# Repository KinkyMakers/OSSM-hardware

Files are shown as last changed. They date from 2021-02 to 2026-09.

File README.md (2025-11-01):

# OSSM - Open Source Sex Machine
### **Maintained by Research and Desire, supported by the community!**
### Check us out at [**researchanddesire.com**](https://researchanddesire.com)

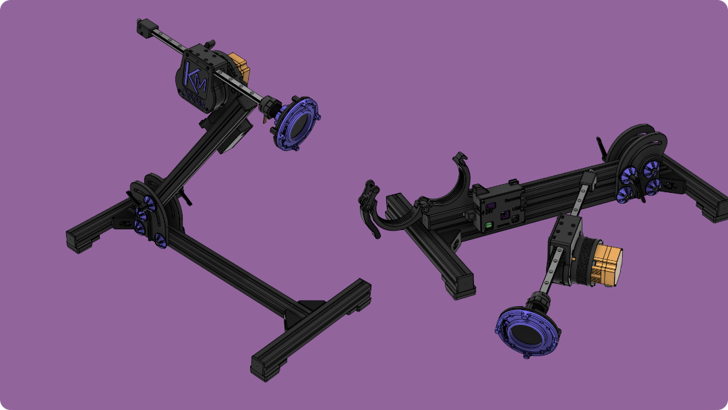
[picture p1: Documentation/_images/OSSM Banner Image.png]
OSSM Overview Image


### [**KinkyMakers Discord Community**](https://discord.gg/VtZcudpxT6) 
  
Most OSSM development takes place through ideas and CAD contributions made by enthusiastic discord members, join the discussion or show off your build!  

### Check out our docs at [GitBook](https://kinky-makers.gitbook.io/)

### [**Read the Frequently Asked Questions**](FAQ.md)

## **Summary**   
**OSSM** (pronounced like "awesome") is a user friendly every day sex machine for the people.

The OSSM's primary feature is that it is a servo powered belt-driven linear rail.  
This allows for quiet, high torque operation at speeds up to 1 meter per second, as well as for software-defined stroke and depth. 

**Standard Recommended Build at a glance**
 - 32 lbs (14 kg) of force @ 20v DC
   - Up to 50 lbs (22 kg) @ 36v DC
 - 8" Stroke (20 cm) with 350mm rail

This project aims to help people curious about sex machines explore their interest.   
A second objective is optionally learning how mechanics, electronics, physics and computing are involved in your sexual pleasure.

### **Primary** Design Goals
- Compact & quiet
- Highly performant
- Moderate cost
- 3D printable
- Easily-sourced components
- Moddable
  
<p align="center">

</p>

Note: This is a _work in progress_ and we have attempted to keep compatibility with the current BOM going
forward, but it's not guaranteed.

### Is it *actually* Open Source?
    CERN Open Hardware Licence Version 2 - Strongly Reciprocal
It is one of a kind Certified, Actual, Factual, Open Source  
[](https://certification.oshwa.org/ca000057.html)

Contributions to this GitHub repository assume the same license.

## **Safety**

The safety of the OSSM is yet to be fully characterized as it is a work in progress.  
The OSSM is a framework for building your own sex machine and as such your specific combination may have risks not inherent to other builds.  
**These risks may be undocumented or undiscovered. Please see the [Hazards](Documentation/Hazards.md) file for more information.**

Use of experimental/modified code increases the level of risk.

While using the OSSM we can suggest the following hierarchy of safety, however it is up to you and your build to decide
what risks exist and how to mitigate them.

1. Have ability to move away
2. Have ability to remove the power
3. If you are in bondage, safety is responsibility of the Top

## **Building Your OSSM**
### Motor Support  
 - 57AIM30 "Gold Motor" (Standard Recommended)
 - 42AIM30 "Round Motor" (Smaller form factor, limited mounting support)
 - iHSV57 "Legacy Motor" (Pre-2024 recommended motor)

The OSSM Software is written to support closed loop servo type motors and tested on the above motors.  
Most OSSM actuator and mounting hardware is designed for NEMA23 form factor motors.  
Attempting to use a stepper or other motor is not recommended; while it may be technically possible in some cases, this usually requires custom design work and advanced-level custom code. 

### Bill Of Materials for Standard Recommended Build

### Electronics  

 - Motor 
   - 57AIM30 ["Gold Motor"](https://www.researchanddesire.com/products/ossm-motor-gold-motor)
     - **Important note:** In order to operate with OSSM Software, motors must receive programming to set their "steps per revolution" to 800.
     - Motors from R+D are pre-programmed for OSSM. Motors from all other sources will need programming.
     - Programming requires a USB to 4 pin RS485 connector, cable for the 8 pin white motor plug, and use of the [Gold Motor Programming Tool](/Hardware/Servo%20Tools/Gold%20Motor/)
 - OSSM Reference Board, Remote, Wiring
    - [OSSM Reference PCB](https://www.researchanddesire.com/products/ossm-reference-board) or ESP32 Development Board
      - More information for board development [here](/Documentation/Board_Design.md).
    - [OSSM Remote](https://www.researchanddesire.com/products/ossm-reference-board)
    - JST-PH 2.0 4-Pin data cable and 16awg power wire
      - [Wire harness - Gold Motor](https://www.researchanddesire.com/products/ossm-wire-harness-gold-motor)
 - 20-36v DC Power Supply (5.5 x 2.1 Barrel Plug)
   - [24 volt 5 amp](https://www.researchanddesire.com/products/ossm-24v-power-supply) is recommended
   - Higher voltage, up to 36v, will provide increased force
   - USB Power Banks capable of true 100w USB PD also generally seem to operate well for a portable OSSM
     - [TESTED: ✓] INIU Power Bank P63-E1 100w (Old model: B63)
     - [TESTED: Powers down on high load] INIU B62 Power Bank 65W

### [**Printed Parts**](Printed%20Parts/) 
 - [Actuator](Printed%20Parts/Actuator/)
   - Body
   - Belt Tensioner
   - Threaded End Effector, Clamp + Nut  
 - [Remote](Printed%20Parts/Remote/)
   - Body
   - Knobs
 - [Toy Mounting](Printed%20Parts/Toy%20Mounting/)
   - Flange Base Plate with Clamping Ring (Tie-Down or Suction)
   - Double Double (Vac-U-Lock)
 - [Mounting](Printed%20Parts/Mounting/)
   - Mounting Ring (PitClamp Mini Ring)
   - Base (PitClamp Mini Base)
   - PCB Enclosure
 - [Stand](Printed%20Parts/Stand/)
   - 3030 Extrusion Base

Experimental parts pop up in the [KinkyMakers Discord](https://discord.gg/wrENMKb3) #ossm-print-testing channel.  
W.I.P. for the top rated to be merged into this repo.

### Standard Actuator Hardware
**GT2 Pulley** 

    (Qty 1) 8mm Bore, 20 Tooth, 10mm Width
**GT2 Timing Belt** 

    (Qty 1) 10mm Width, 500mm length
**MGN12H Rail + Bearing Block**

    (Qty 1)
    Minimum 250mm
    Suggested 350mm
    Maximum 550mm

Rail length = desired maximum stroke + 180mm  
Must be MGN**12H** rail.  
H is a longer bearing block than C for greater stability. 12 indicates 12mm rail width.

**Ball Bearings**

    (Qty 6) MR115-2RS 5x11x4mm 

**Fasteners**  

    (Qty 8) M3x8  Socket Cap Head Bolt 
    (Qty 2) M3x16 Socket Cap Head Bolt 
    (Qty 1) M3x20 Socket Cap Head Bolt 
    (Qty 7) M3 Hex Nut
    (Qty 3) M5x20 Socket Cap Head Bolt
    (Qty 1) M5 Hex Nut
    (Qty 4) M5x35 Socket Cap Head Bolt 
    (Qty 4) M5 20mm Hex Coupling Nut (Or M5 Hex Nut)

**Additional hardware is required for Stand, Mounting, Remote  
Detailed in their respective [Printed Parts](Printed%20Parts/) folder**

## Assembly

**Important note:** The actuator rail direction is critical for pattern accuracy and safety functions. The proper direction is with the threaded end to the right when looking at the front face of the actuator body - the "M" side of the OSSM text on the Cover.  
Outdated videos and documentation may show different directions. Your rail should extend the threaded end first when booted; if this does not match the behavior of your build you should reverse your rail's printed hardware.

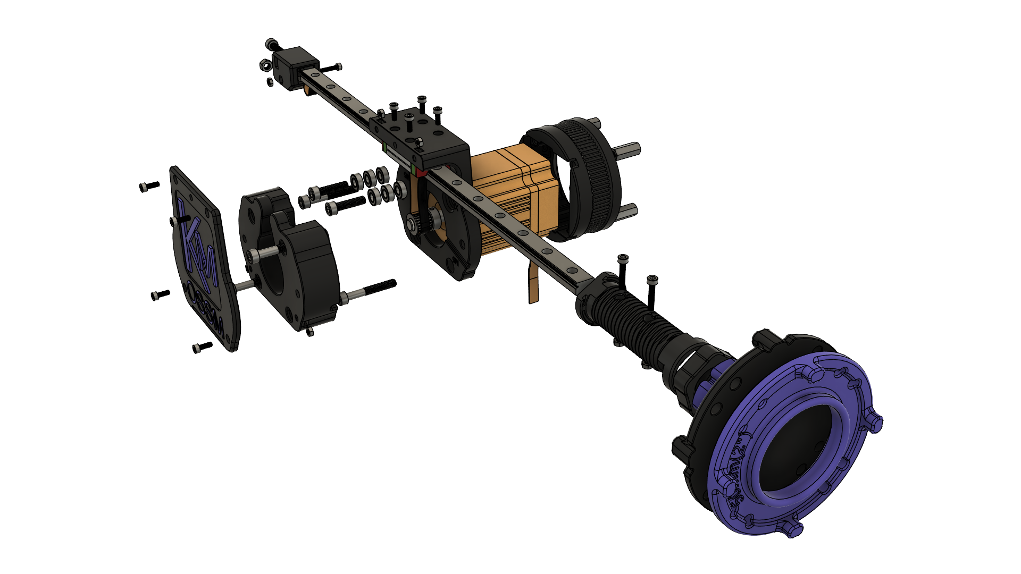
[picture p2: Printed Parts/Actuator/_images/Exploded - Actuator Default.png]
  
### [**Build Instructions**](Documentation/Assembly%20Instructions.pdf)
(03.30.2025) Note: There have been recent improvements to the OSSM Standard Recommended build that are not yet reflected in this build document.  
Refer to exploded views from the Printed Parts folders for assembly of each major component.
## Build Videos

[OSSM Assembly Playlist](https://youtube.com/playlist?list=PLzSK7OAu3KNQsFo6WJGT8P28lfkD3xpps)

[OSSM Complete Assembly - Follow Along Guide](https://www.youtube.com/watch?v=9lVobSEw_Uw)

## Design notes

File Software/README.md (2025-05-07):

## Requirements:
- PlatformIO
- ESP32 microcontroller

If you aren't sure what ESP board to select in PlatformIO, choose "ESP32 Dev Module" - it works on all ESP32 I have tested so far.

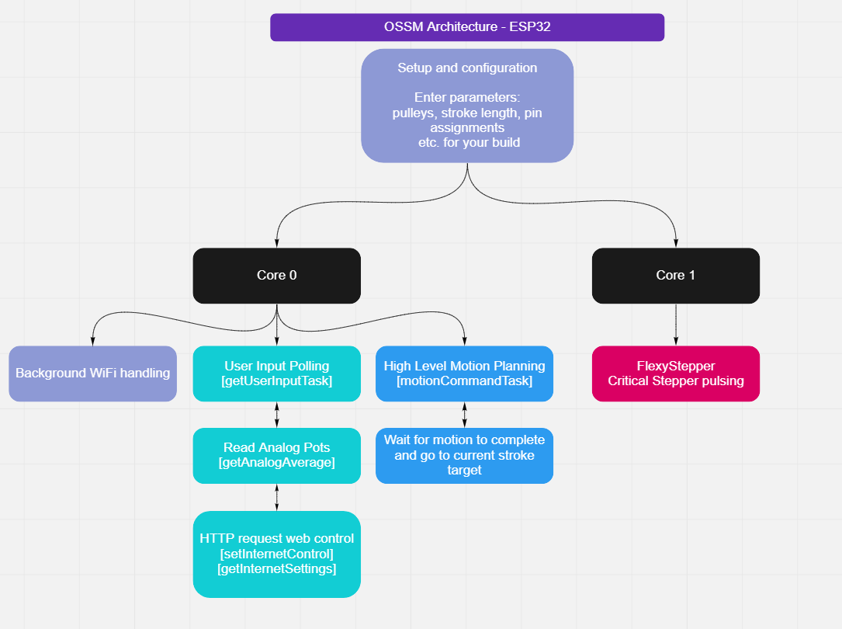
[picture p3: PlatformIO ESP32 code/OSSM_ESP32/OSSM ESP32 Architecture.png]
ESP32 Architecture


## Logging

This project uses ESP32's [native logging library](https://docs.espressif.com/projects/esp-idf/en/stable/esp32/api-reference/system/log.html).

## Commands

**Upload and monitor**
```bash
pio run -t upload -t monitor
```

**Run Unit Test tests**
```bash
pio test -e test
```

## Other Documentation
- [Git Branching Strategy](docs/Git Branching Strategy)

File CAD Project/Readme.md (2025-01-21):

    Work in progress.
    
    TODO: 
      3030 Extrusion Stand Assembly
      Add "OSSM - Mod" multiple-component project template
      Determine if Hardware components should be "independent"
        For now - designer's preference
        Independent could allow a scripted hardware count

# Design Guidelines For Contributions

- **Template**: Contribution basic template is located in [./Templates/](Templates)
    - Replace "Project Name" in Document and Component with your Project Name

User-contributed Projects with a file structure following these guidelines will allow for the easiest incorporation into an official OSSM release.

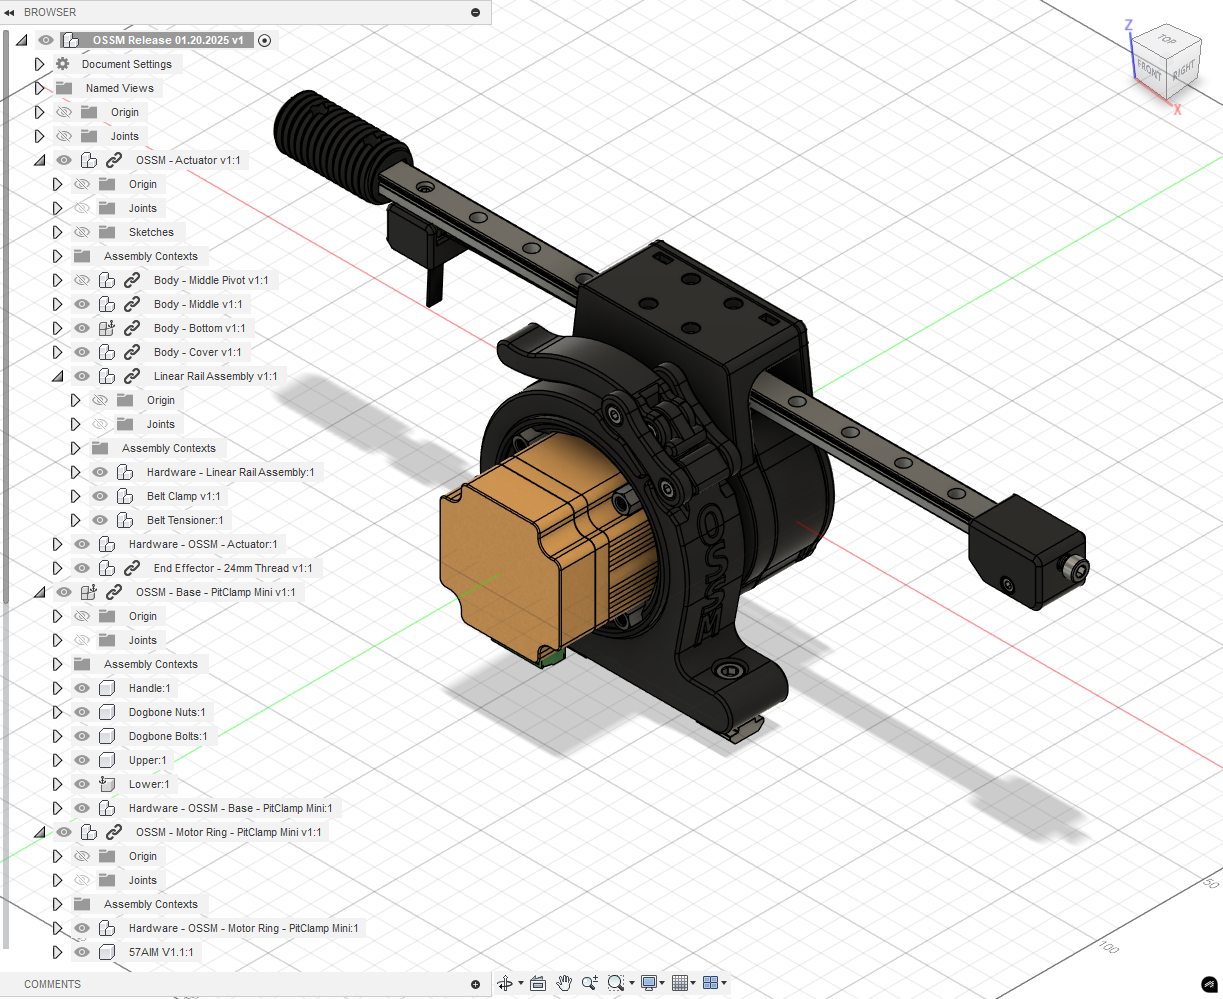
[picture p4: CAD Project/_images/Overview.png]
CAD Project Overview


## Fusion File Structure:
    ProjectName
        (Bodies)
          <empty>
        (Component)ComponentNameOne
          (Bodies)
            ...
        (Component)ComponentNameTwo
          (Bodies)
            ...
        (Component)Hardware - ProjectName 
          (Bodies)
            <empty>
          (Component)HardwareName:1
            (Bodies)
              ...
          (Component)HardwareName:2
            (Bodies)
              ...

## Naming Conventions

- **Disallowed/Special-Use Characters**: These characters are reserved for special behavior for documentation scripting and have rules for being part of the Document or Component names.
  - `.` Designates file extension (dot)
    - Allowed for use in versioning e.g. `V1.1`
  - `-` Designates parent-child Component relationship
    - Allowed for use in hardware names e.g. `M5 T-Nut`
  - `_` Designates a Component (underscore) *[Disallowed]*
  - `[]` Designates reuse of hardware (brackets)
  - `()` Designates special hardware instructions (parentheses)

- **Single Component Project**: If your Project will only have a single Component for printing, it should contain only one Component named identical to the ProjectName.

- **Parent-child Component Relationship**: If your part should be considered as a primary item for a Parent Component, indicate this by referencing the Parent Component by exact name, followed by ` - ` and then the name of your Child Component.
  - Example: `End Effector - 24mm Short` will cause the release file to be located in the 'End Effector' directory of files, named '24mm Short'.
  - At this time, only one Parent-child relationship is allowed per Document, and must be on a single level.
    - *Documents may be nested as linked Components for more complex Parent-child relationships.*

- **Version Increment**: If your part is an update from the initial release, append ` V#.#` (uppercase, case sensitive) to the Component Name, representative of Major.Minor updates.
  - Example: `Ring V1.1`

- **Includes Hardware**: If your part requires hardware, all hardware should be nested as Components in a single top-level Component `Hardware - ProjectName`
  - Example: `Hardware - Body - Middle` where `Body - Middle` is the ProjectName

- **Reused Hardware**: If your part reuses hardware from a part it will be replacing, note this by appending ` [From:{Component}]` to the Component name.
  - Example: `M3 x 8 Cap Head Bolt [From:OSSM - Body - Middle]`

- **Alternative Hardware**: If an alternative hardware can be used, note this by appending ` ({Specification} alternative)` to the Component Name.
  - Example: `M4x12 Cap Head Screw (M4 x 10 alternative)`

- **Variant Hardware**: If hardware should vary for a different type of hardware a user could have, note this with `({Specification} for {variant},{Specification2} for {variant2})` in the Component Name. 
  - Example: `(M6 x 15 Cap Head Screw for 3030 Extrusion,M6 x 20 Cap Head Screw for 4040 Extrusion)`

## Running a Release from Fusion

This section serves as documentation for OSSM Project Leads.

There is a proof of concept "Release" process that may evolve over time, but it relies on the above conventions being followed strictly.

### Future Work:
- Convert `.stp` to `.stl` at high-quality refinement and bundle into `OSSM-Hardware/Hardware/OSSM Printed Parts` release.
- Generate hardware documentation from `Hardware` named component structures.

### Steps:

1. Update the Fusion Document name to `OSSM Release $MM.DD.YYYY`.
2. Export your Fusion Document as `OSSM.f3z` to overwrite the current file.
3. Run the Add-In "ExportIt" using the settings below. This will populate the `_export` directory with `f3d` and `step` folders.
4. Run `OrganizeForRelease.ps1` in a PowerShell terminal from the directory containing the `_export` folder, next to `OSSM.f3z` 
  - This will create a `RELEASE` folder with the date appended 
  - Files will be organized in a release configuration
    - `.f3d` is grouped based on Fusion nested structure
    - `.stp` is grouped based on naming convention, children grouped into parent
    - [Future] Documentation framework generated referencing files contained in `Hardware` directories 
5. Manually tidy up:
   - Move the previous release to the `_archive` folder.
   - Check for loose files in `_export` and remove them.
     - (This may suggest something went wrong generating your release)

### ExportIt Settings

#### Export Tab
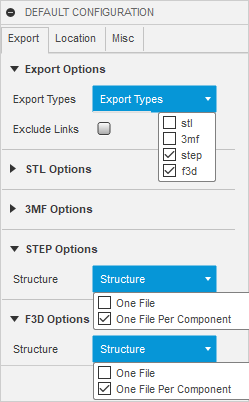
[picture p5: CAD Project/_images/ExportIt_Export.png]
ExportIt Export Tab Settings


#### Location Tab
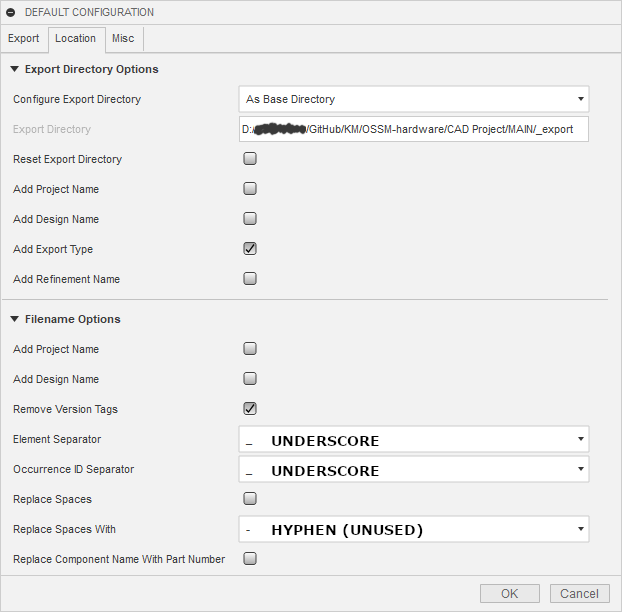
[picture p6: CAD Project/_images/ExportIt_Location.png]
ExportIt Location Tab Settings


#### Misc Tab
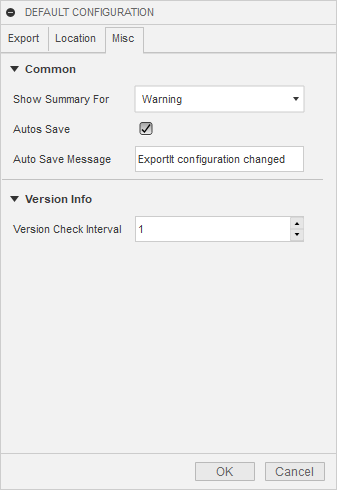
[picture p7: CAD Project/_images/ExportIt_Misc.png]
ExportIt Misc Tab Settings


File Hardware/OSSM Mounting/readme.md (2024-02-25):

# Mounting Options

There are several options for mounting your OSSM! You will find descriptions of the mounts below, and the files and instructions on how to build them in the folders above. 

The **OSSM Basic Mount** is the "official" design and is available to [purchase from Research and Desire](https://shop.researchanddesire.com/collections/all/products/ossm-basic-mount). It is mostly 3D printed and is screwed down to a piece of wood, furniture, shelf etc. It uses the 3D printed middle pivot and threaded handles. Current design relies on sourcing a length of 3030 extrusion (1.5" will also work). This is one of the less expensive options. Picture below.

rdmount

The **Shicks 4040 mount** was created by discord community member Shicks101 (Thanks!) and is made out of Aluminum Extrusion and 3D printed parts. It supports a high level of articulation and variability in height. The parts are easy to get, but it is a little more costly. You may need to weigh it down with dumbbells or sandbags. Picture below.

resized

The **OSSM Extrusion Mount** is an extrusion based mount that is simple to print and assemble requiring no cutting tools if you can get extrusion at the correct length. It uses the standard middle pivot and only a few 3D printed pieces.


**Emma's mod** is for the use of a long Nema23. This mount is mostly 3D printed and was created for a different machine, but will still work. (no photo available)  

There are a few more mounting options created by community members in the Discord that are not present here in the repository. Some are motorized! Or if none of these fit your use case, you could create your own and share it with the community.

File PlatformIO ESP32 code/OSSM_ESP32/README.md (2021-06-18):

# OSSM Software
This is the recommended software for use with OSSM designs

### Requirements:
- Arduino IDE or PlatformIO
- ESP32 microcontroller

To use with Arduino, simply open the .ino file in the src directory. You will also need to copy the folders in the lib directory to your arduino library folder on your PC.

Use the tutorial below to install the ESP32 board into your Arduino IDE so you're ready to program!

[Setting up ESP32 on Arduino IDE](https://randomnerdtutorials.com/installing-the-esp32-board-in-arduino-ide-windows-instructions/)

If you aren't sure what ESP board to select in Arduino IDE, choose "ESP32 Dev Module" - it works on all ESP32 I have tested so far.

ESP32 Architecture

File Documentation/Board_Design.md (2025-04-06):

//TODO: This document is in need of an update.

We have found that the 3.3v boards may miss steps at high speed, so please use a level shifter as well.  
To start working on the project, something like this [Adafruit board](https://www.adafruit.com/product/3405) is an excellent place to start.  
Accessories required for prototyping
    include [Breadboard](https://www.amazon.ca/Breadboard-Solderless-Prototype-Distribution-Connecting/dp/B01EV6LJ7G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)
    and [Dupont Jumpers](https://www.amazon.ca/120pcs-Multicolored-Breadboard-Arduino-raspberry/dp/B01LZF1ZSZ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)

## Official OSSM Wiring

OSSM reference board front  

The above image is of a version 1 reference board.

### OSSM PCB Connections

OSSM PCB connection diagram

### GPIO Layout

OSSM pinout diagram
JST Header location with pin labels

## Non-Official OSSM Wiring

This should be a good start for the wiring of your OSSM! However, depending on your hardware mix settings or wiring may
be different

### OSSM PCB w/ TB6600 Stepper Driver

OSSM PCB w/ TB6600 Stepper Driver

### Servo Wiring

Servo Wiring

### Stepper Wiring

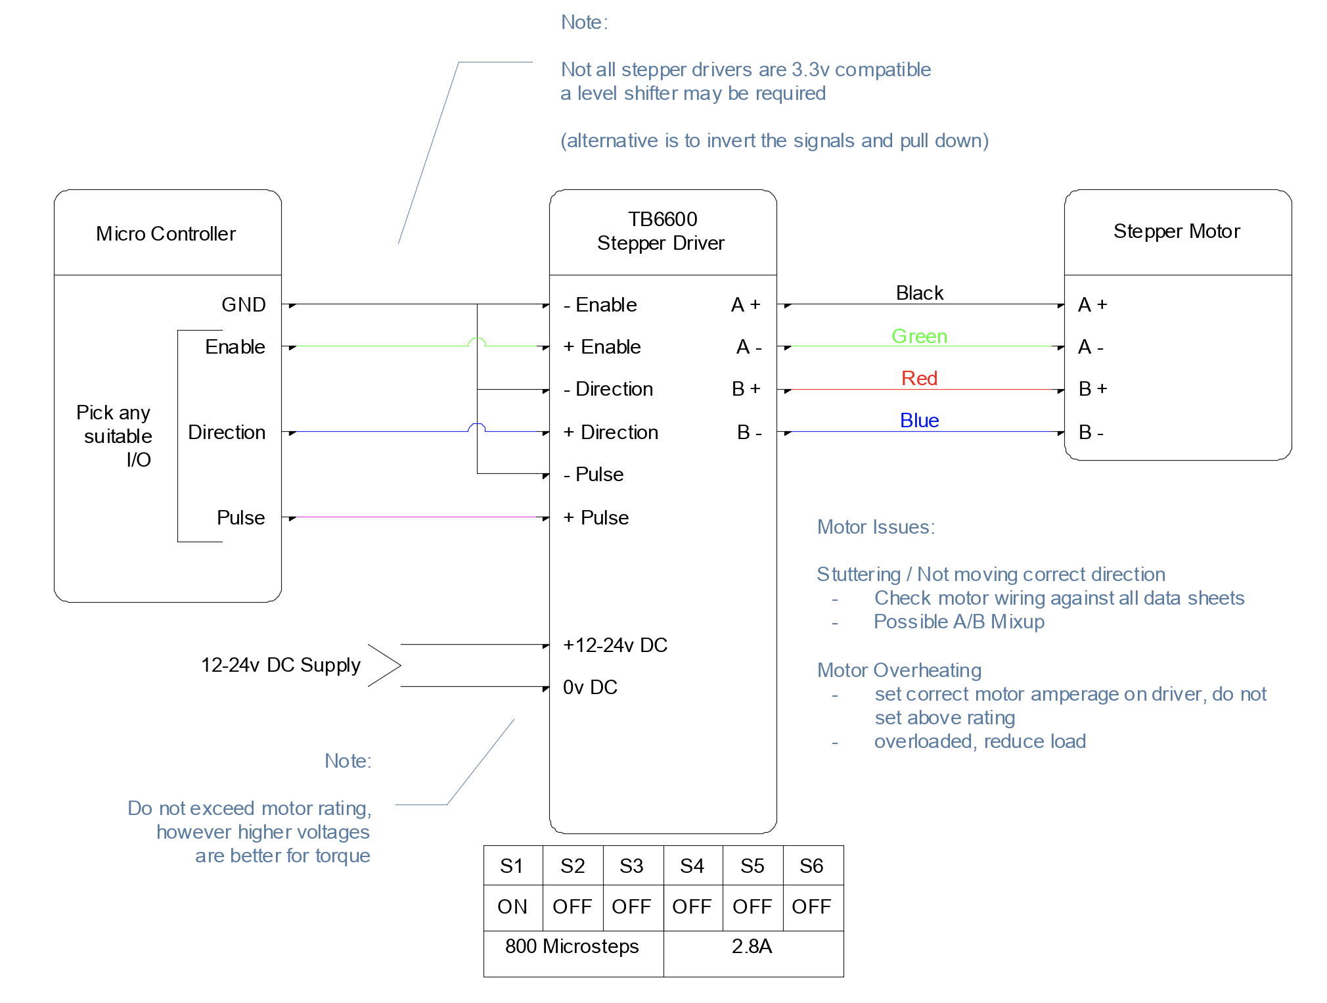
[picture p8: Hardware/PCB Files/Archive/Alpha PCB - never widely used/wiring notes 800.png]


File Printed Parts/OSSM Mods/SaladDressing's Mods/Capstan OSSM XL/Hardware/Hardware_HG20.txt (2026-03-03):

4x M4x12 ISO7380

2x M5x45 Countersunk
4x M5x75 Countersunk
4x M5x20 Hex Cap
2x M5x25 Hex Cap
3x M5x30 Hex Cap
4x M5x65 Hex Cap
1x M5x110 Hex Cap Fully threaded https://de.aliexpress.com/item/1005005879037174.html?gatewayAdapt=glo2deu

11x M5 Nuts
4x M4 Nuts

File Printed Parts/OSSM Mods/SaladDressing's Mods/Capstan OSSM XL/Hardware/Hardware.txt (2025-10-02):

5x M3x12 Hex Cap
2x M3x16 Hex Cap
4x M4x12 ISO7380
4x M5x45 Hex Cap
1x M5x80 Hex Cap Fully threaded
6x M5x45 Countersunk
1x M5x12 ISO7380
2x M5x20 ISO7380

13x M5 Nuts
3x M3 Nuts
4x M4 Nuts

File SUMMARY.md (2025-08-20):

# Table of contents

* [OSSM - Open Source Sex Machine](README.md)
* [Contributor Covenant Code of Conduct](CODE_OF_CONDUCT.md)
* [Contributing to OSSM (Open Source Sex Machine)](CONTRIBUTING.md)
* [Frequently Asked Questions](FAQ.md)
* [CAD Project](<CAD Project/Readme.md>)
  * [MAIN](CAD Project/Main/README.md)
    * [OSSM CAD Project Release Notes](<CAD Project/MAIN/RELEASE_NOTES.md>)
* [Documentation](Documentation/README.md)
  * [Assembly Instructions](<Documentation/Assembly Instructions.md>)
  * [Board\_Design](Documentation/Board_Design.md)
  * [New Standard Servo Motor](Documentation/Gold-Motor.md)
  * [Hazards](Documentation/Hazards.md)
  * [Safety and designing for the OSSM](<Documentation/Safety and Design Guide.md>)
* [Software](Software/README.md)
  * [OSSM Project Documentation](Software/docs/README.md)
    * [PlatformIO](Software/docs/PlatformIO.md)
  * [Include Directory](Software/include/README.md)
  * [Libraries Directory](Software/lib/README.md)
    * [StrokeEngine](Software/lib/StrokeEngine/README.md)
      * [CHANGELOG](Software/lib/StrokeEngine/CHANGELOG.md)
      * [Pattern](Software/lib/StrokeEngine/Pattern.md)
      * [Examples](Software/lib/StrokeEngine/examples/README.md)
  * [Testing](Software/test/README.md)
* [Hardware](Hardware/README.md)
  * [Mounting Options](<Hardware/OSSM Mounting/readme.md>)
    * [Deprecated - Ball Head Mount](<Hardware/OSSM Mounting/Deprecated - Ball Head Mount/readme.md>)
    * [OSSM - Basic Mount](<Hardware/OSSM Mounting/OSSM - Basic Mount/README.md>)
    * [OSSM - Extrusion Mount](<Hardware/OSSM Mounting/OSSM - Full Extrusion Mount/README.md>)
    * [Shicks 4040 mount](<Hardware/OSSM Mounting/Shicks 4040 mount/Readme.md>)
      * [Modified 4040 parts](<Hardware/OSSM Mounting/Shicks 4040 mount/aluxprofile/README.md>)
  * [Printing the parts!](<Hardware/\[LEGACY] OSSM Printed Parts/README.md>)
    * [Choose your method for attaching a toy to the OSSM](<Hardware/\[LEGACY] OSSM Printed Parts/end effector options/README.md>)
      * [24mm Threaded Option](<Hardware/\[LEGACY] OSSM Printed Parts/end effector options/24mm threaded/README.md>)
  * [PCB Files](Hardware/PCB Files/README.md)
    * [OSSM Remote V2](<Hardware/PCB Files/OSSM Remote V2/README.md>)
  * [Servo Tools](Hardware/Servo Tools/README.md)
    * [Gold Motor](<Hardware/Servo Tools/Gold Motor/readme.md>)
* [Printed Parts](Printed Parts/README.md)
  * [Actuator](<Printed Parts/Actuator/README.md>)
  * [Mounting](<Printed Parts/Mounting/README.md>)
    * [PitClamp Mini](<Printed Parts/Mounting/PitClamp Mini/README.md>)
      * [ASSEMBLY\_GUIDES](<Printed Parts/Mounting/PitClamp Mini/ASSEMBLY_GUIDES.md>)
      * [PitClamp Mini Bill Of Materials](<Printed Parts/Mounting/PitClamp Mini/BOM.md>)
      * [UPDATES](<Printed Parts/Mounting/PitClamp Mini/UPDATES.md>)
  * [OSSM - Remote](<Printed Parts/Remote/README.md>)
  * [Stand](<Printed Parts/Stand/README.md>)
  * [OSSM Mods](Printed Parts/OSSM Mods/README.md)
    * [PitClamp Mini Reinforced 3030 Hinges](<Printed Parts/OSSM Mods/PitClamp Mini Reinforced 3030 Hinges/README.md>)
    * [PitClamp Mini Reinforced Standard](<Printed Parts/OSSM Mods/PitClamp Mini Reinforced Standard/README.md>)
    * [Threaded Belt Clamp V2](<Printed Parts/OSSM Mods/Threaded Belt Clamp V2/README.md>)

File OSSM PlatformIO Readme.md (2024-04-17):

OSSM has been developed in PlatformIO.  For people used to the Arduino IDE, moving to PlatformIO can seem daunting.  Trust us that it is simpler than it looks to operate and works far better than the very basic Arduino IDE as the project grows and changes.  

This is particularly important when it comes to managing all the libraries and dependencies. This gets very complex, very quickly. Earlier builds of OSSM it was sort of possible to mash it into the Arduino IDE and get a compile happening.  It has now past the point when it is easier to teach you to use PlatformIO than it is to repackage OSSM for the Arduino at each release. 

Why? More time for coding features and easier collaboration! OSSM is moving fast. Once you get used to VSCode there are some other great features such automatic downloads from Github and linting (autocomplete for code). 

1. Start by installing VSCode and the PlatformIO extension. There are plenty of guides for this on the web.  

2. Restart VSCode wait until PlatformIO has started and look on the sidebar for this button.



3. Click "Open"



4. This will pop up 



5. Click "Open Project" and search for the OSSM directory that has platformIO.ini in it





6. In the src directiory you should find main.cpp, click on that 



7. Near the bottom of the window look for a tick (compile) and an arrow (upload) 

 

8. You can then compile or skip that step and upload directly to your board.  

What if that doesn't work?  Check the debug screen but chances are you have not selected the right Com port for the OSSM board or the wrong board for the project.  

9. COM or /DEV/TTY will vary from machine to machine. It is set here in platformIO 



11. The reference board for OSSM has an embedded "Espressif ESP32 Dev Module".

12. If the project fails to build and the upload fails DON'T PANIC! Chances are there has been some kind of external library update.  Try changing the following lines in platformIO.ini in the root of the project 

"platform = espressif32"   to "platform = espressif32@3.5.0"

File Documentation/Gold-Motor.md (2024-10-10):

# New Standard Servo Motor

## 57AIM30 - Gold Motor

We have been testing and have decided on a new motor as the build standard. It has the same mounting pattern and shaft diameter as the old motor (iHSV57-30-XX).
It is sold by Research and Desire as [Gold Motor](https://www.researchanddesire.com/products/ossm-motor-gold-motor) or available generically as 57AIM30

If you wish to order a 57AIM30, you should source a model that runs at 1500 RPM and has an RS485 interface (NOT the 3000 RPM or CANBUS versions)

Also note that if you source your motor from somewhere other than R&D, you will need to reprogram the stored settings with a USB to RS485 dongle using the scripts found [here](https://github.com/KinkyMakers/OSSM-hardware/tree/master/Hardware/Servo%20Tools/Gold%20Motor) before you can use it.

Advantages:

- Cheaper (20%) - dependant on availability and location.
- Smaller (40% length of 180W standard - i.e. 60% reduction!).
- Lighter (50% weight of 180W).
- Higher peak force (30% higher in real-world test).
- Better over-torque handling - can be configured to reduce torque output instead of disable like current 180w servo.
- Is drop-in replacement for iHSV57 series making BOM compatible.

Requirements:
- Requires V2.2 PCB or newer for  simple wiring with PH-4 cable
  - Older boards will need wires soldered to 10 pin header
  - Recommend adding 1500uF capacitor, min 50V to older boards <V2.3

Disanvantages:

- More efficient (this causes more regenerated power in some motion conditions which requires additional capacitance and handling on the PCB).
  - PCB v2.3 as currently sold by R&D or listed on this repo has added capacitor. If you are upgrading your motor, you should add the capacitor as shown below.
- Digital comms over RS485 (Not worse than current RS232, just current boards don't have the needed adapter).
- Requires software setup to see full benefits (default FW settings disable motor in over-torque condition).
- If modding your software, technically lower top speed than HSV. (Standard code speed limit is lower than gold motor limit, so not a disadvantage for regular user).

## 42AIM30 - Gold Motor 42 (variant)

In addition to 57AIM30 (Gold Motor), which fits exactly to the previous designs and specs with no extra work, there is a varient motor which has exactly same internals and specs.
The 42AIM30 (see notes above for ordering the correct model) does away with the heatsink housing and is purely the cylindrical motor with connectors at the base.

Advantages (compared to 57AIM30):

- Smaller diameter (26%) - plus cylinder vs square.
- Lighter (unknown - ~25%?) - please submit mass if you have one.

Disadvantages (compared to 57AIM30):

- Much harder to mount.
  - No _mounting ears_ to bolt through, must put exact length machine screws into face of motor.
  - Current standard housings are not compatible with 42AIM30, though there are some options available via discord.
- Suspected heat issues caused by lack of heat sink and enclosure in printed housing - more data needed.
- Lack of clear advantages over Gold Motor (57AIM30)
  - Same specs.
  - Same length.
  - Same disadvantages.
  - Changes to BOM required.

OSSM Gold Motor Wiring





OSSM Capacitor view

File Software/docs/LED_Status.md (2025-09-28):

# (WIP) RGB LED Status Indication

The RGB LED (connected to pin 25) provides visual feedback for both Bluetooth Low Energy (BLE) connection status and machine operational status.

## Status Priority

Machine operational status takes priority over BLE status:
1. **Homing** (highest priority) - Deep purple breathing effect
2. **BLE Status** (lower priority) - When machine is idle

## Machine Status Indications

### When Machine is Homing
- **Deep purple breathing effect** - Smooth breathing pattern

- Continues until homing is complete or fails

## BLE Status Indications

### When BLE Advertising (looking for connections)
1. **Rainbow effect** - 1 second
2. **Fast breathing blue** - Rapid breathing effect in blue color (10x faster), continuously while advertising
3. **Auto-dim after 30 seconds** - Dims to subtle pulsing at connection level brightness to reduce annoyance

### When BLE Connected
1. **Rainbow effect** - 1 second
2. **Fade to dim** - Blue LED fades to a low dim level (~12% brightness) and stays dimmed
3. **Communication pulses** - Subtle brightness increases during BLE communication (send/receive)

### When BLE Disconnected
- **LED Off** - No light

## Advertising Timeout Feature

To reduce visual distraction for users with wired remotes, the LED automatically dims after 30 seconds of advertising:

- **First 30 seconds**: Bright fast pulsing blue (easily visible when searching for device)
- **After 30 seconds**: Dims to connection-level brightness (~12%) with gentle pulsing
- **Purpose**: Maintains indication that BLE is available while reducing annoyance
- **Reset**: Returns to bright pulsing if BLE connection status changes

## Communication Indication

When BLE is connected and dimmed, the LED will briefly pulse brighter during:
- **Receiving commands** from connected device
- **Sending responses** back to connected device  
- **State updates** sent to connected device

The communication pulse is a subtle 100ms fade with minimal brightness increase.

## Technical Notes

- **Advertising timeout**: Controlled by `ADVERTISING_TIMEOUT` constant (30 seconds)
- **Dimmed advertising**: Uses `showBLEAdvertisingDimmed()` function with gentle pulsing range
- **Auto-reset**: Timeout resets when BLE status changes (connect/disconnect)

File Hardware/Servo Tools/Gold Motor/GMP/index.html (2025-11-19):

Gold Motor Control

Connection Instructions:
Connect the motor using an RS485 USB adapter that provides 5V+, GND, A, B. Example (https://www.amazon.com/CERRXIAN-Terminal-Converter-Serial-Windows/dp/B09JMT9D59)
The motor must have 20-36V DC supplied, which can come from the OSSM Reference Board or external power source.
Important:
The OSSM Reference Board 4-Pin Signal Plug must be disconnected while programming.

Connect to Motor Disconnect

## Motor Settings

Reset fields to OSSM Standard

Electronic Gear Denominator (Steps per Revolution) 0x0B

Still Maximum Allowed Output 0x18

Speed Ring Proportional Ratio Coefficient (KP) 0x05

Position Ring Proportional Coefficient (KP) 0x07

Direction Polarity 0x09

Hack the planet?

Show Advanced Settings

Warning: Advanced settings are experimental.
Changing these values may make your motor unusable until settings are restored.
Please save your current settings somewhere safe before making changes.

MODBUS Enable 0x00

Drive Output Enable 0x01

Motor Target Speed 0x02

Motor Acceleration 0x03

Weak Magnetic Angle 0x04

Speed Loop Integration Time 0x06

Speed Feed 0x08

Electronic Gear Molecules 0x0A

Target Location is 16 bits Lower 0x0C UNSUPPORTED

Target Position is 16 bits High 0x0D UNSUPPORTED

Alarm Code 0x0E

System Current 0x0F UNSUPPORTED

Motor Current Speed 0x10 UNSUPPORTED

System Voltage 0x11 UNSUPPORTED

System Temperature 0x12 UNSUPPORTED

The PWM of the System Output 0x13 UNSUPPORTED

Parameter Saving Flag 0x14

Device Address 0x15

Absolute Position is 16 bits Lower 0x16 UNSUPPORTED

Absolute Position is 16 bits Higher 0x17 UNSUPPORTED

Specific Function 0x19

Write Settings Read Registers

## Register Values

Gold Motor Programming Utility
v2.0 alpha

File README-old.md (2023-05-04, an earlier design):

# OSSM - Open Source Sex Machine
OSSM (pronounced like "Awesome") is a user friendly every day sex machine for the people.

This project aims to help people curious about sex machines explore their interest. A second objective is optionally learning how mechanics, electronics, physics and computing are involved in your sexual pleasure.

Please note that this is a _work in progress_ and we have attempted to keep compatibility with the current BOM going forward, but it's not guaranteed.

*Primary design goals* are to make a machine that is Compact, Quiet, Moderate cost, 3D printable (no cutting/machining), High performance, flexible, Easily sourced components, Doesn't look like a giant machine.
<p align="center">

</p>

## Getting Started

<h3><p align="center"><a href="FAQ.md">Read the Frequently Asked Questions</a></p></h3>

There are a few hardware flavours to choose from, we've included user modified versions in case that fits your use case better!

<h3><p align="center"><a href="https://github.com/KinkyMakers/OSSM-hardware/blob/master/Documentation/Assembly%20Instructions.pdf">Build Instructions</a></p></h3>

Join our Discord to be part of the discussion and get help with your build. We have a huge community of makers! https://discord.gg/MmpT9xE

<p align="center">

</p>

### Software

The software is available in this github repository, the software is written and compiled utilizing PlatformIO on Visual Studio Code. <a href="OSSM PlatformIO Readme.md">Reference for working with the code in PlatformIO here</a>

We recommend using the ESP32 microcontroller. This code is still arduino IDE compatible but offers many times better performance and a nice internet dashboard you can use!
Control your OSSM at https://app.researchanddesire.com/ossm !

### Eagle PCB
Simple PCB to power an ESP32 (wifi enabled microcontroller) from 24V and breakout the pins for the OSSM control

### Mechanical design
The OSSM use a compact belt design with components that have become widely available due to 3D printing popularity.
It is driven by a Nema23 motor of **your** choosing, although we reccomend small integrated closed loop servos for their silent operation and very high performance.
<p align="center">

</p>

### Safety

The safety of the OSSM build is yet to be fully characterized as it is a work in progress. The OSSM is a work in progress and as it is a framework for building your own sex machine your specific combination may have risks not inherent to other builds. These risks may be undocumented. 

While using the OSSM we can suggest the following heiracrhy of safety, however it is up to you and your build to decide what risks exist and how to mitigate them. 

- A) Have ability to move away
- B) Have ability to remove the power
- C) If in bondage, that is responsibility of the Top

## Bill Of Materials

We are calling this the reference build, when deviating from it please check compatability with existing BOM

1) **[3D Printed Parts](Hardware/OSSM%20Printed%20Parts)**
   - This has recently had significant changes
   - [Make sure to choose one of the options for the toy adapters](Hardware/OSSM%20Printed%20Parts/end%20effector%20options)
   - Mounting options are still something that need to be worked on
   - Thank you @Elims for the [belt tensioner design](https://media.discordapp.net/attachments/756320102919700607/858110808281317396/unknown.png) ( https://github.com/theelims/FuckIO )
2) **IHSV57 NEMA23 Servo with 8mm shaft** : [Amazon.ca](https://www.amazon.ca/Integrated-Servo-Motor-IHSV57-30-10-3000rpm/dp/B081CVJHC7) | [JMC](https://www.jmc-motor.com/product/953.html)
   - *Avoid the StepperOnline version until we can further test*
   - Make sure you get something with **8mm** shaft.
   - There are *3* sizes of this motor.  100W = iHSV57-30-**10**, 140W = iHSV57-30-**14**, 180W = iHSV57-30-**18** 
   - Prefer motors with firmware version 6 (shown as `V60x`)
   - Search around for the best deal for you - reccommend searching "ihsv57" on Aliexpress.com and choosing the -10 -14 or -18
   - For details on picking the right motor for your use case - check this [FAQ](https://github.com/KinkyMakers/OSSM-hardware/blob/master/FAQ.md#q--what-strength-of--motor-do-i-need)
   - If you are using the 140W or180W version it is recommended to use a 10mm wide belt and pulley (see the next two items)
3) **GT2 Pulley 8mm Bore 20 Tooth, 10mm width** : [Amazon.ca](https://www.amazon.ca/Timing-Pulley-8mm-bore-10mm-belt-20-Tooth/dp/B09L7D7HHT)
4) **GT2 Timing Belt - 10mm width** : [Amazon.ca](www.amazon.ca/Timing-Meters-Creality-Anycubic-Printer/dp/B097T4DFM6/)
* Your desired stroke length plus about 200mm should be your minimum order length
5) **Bearings** 5x11x4mm : [Amazon.ca](https://www.amazon.ca/gp/product/B07CVBW44R/ref=ppx_yo_dt_b_search_asin_title?ie=UTF8&psc=1)
6) **MGN12H Rail and bearing** : [Amazon.ca](https://www.amazon.ca/Usongshine-guidage-lin%C3%A9aire-MGN12H-300mm/dp/B07XLL484J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)
   - Minimum 250mm in length
   - Rail length = desired stroke + 180mm
   - Must be MGN12**H** rail
7) **Power Supply** : 24v 4-5A w/ 2.1mm DC plug - (need to update reference link)
   - Larger motors generally need more power. 
   - 180W -> 24V 5A
   - 140W -> 24V 4A
   - 100W -> 24V 4A
   - The OSSM will work even with small power supplies, but will be limited on maximum force
   - Ensure the power supply is fully enclosed (like a laptop power supply)
   - Ensure the power supply has the correct approvals for your location - This really helps ensure performance as well!
   - Use a good quality power supply from a reputable manufactuer. There have been reports of electromagnetic interference causing unpredicable OSSM operation created a safety hazard. Cheap power supplies also can have wildly optomistic voltage and amperage ratings, 
8) **Metric Cap Screws** : [Amazon.ca](https://www.amazon.ca/Comdox-500pcs-Socket-Screws-Assortment/dp/B06XQLTLHP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)
   - A kit like this will provide what's needed:
   - 4x m5x20
   - 1x m5x12 (can also use m5x20)
   - 10x m3x8
   - 2x m3x16
   - 8x m5 nuts
   - 8x m3 nuts
9) **ESP32 Development Board**  
  
   - [An official OSSM reference PCB](https://research-and-desire.myshopify.com/collections/all/products/ossm-reference-board) 
   - We do not currently have a best suggestion if you are not using a reference board, most generic development boards are the same
   - We have found that the 3.3v boards may miss steps at high speed, so please use a level shifter as well. 
   - To start working on the project, something like this [Adafruit board](https://www.adafruit.com/product/3405) is an excellent place to start.
   - Accessories required for prototyping include [Breadboard](https://www.amazon.ca/Breadboard-Solderless-Prototype-Distribution-Connecting/dp/B01EV6LJ7G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) and [Dupont Jumpers](https://www.amazon.ca/120pcs-Multicolored-Breadboard-Arduino-raspberry/dp/B01LZF1ZSZ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)

## Official OSSM Wiring



### OSSM PCB Connections



### GPIO Layout

OSSM pinout
JST Header

## Non-Official OSSM Wiring

This should be a good start for the wiring of your OSSM! However, depending on your hardware mix settings or wiring may be different 

### OSSM PCB w/ TB6600 Stepper Driver



### Servo Wiring



### Stepper Wiring 

wiring notes

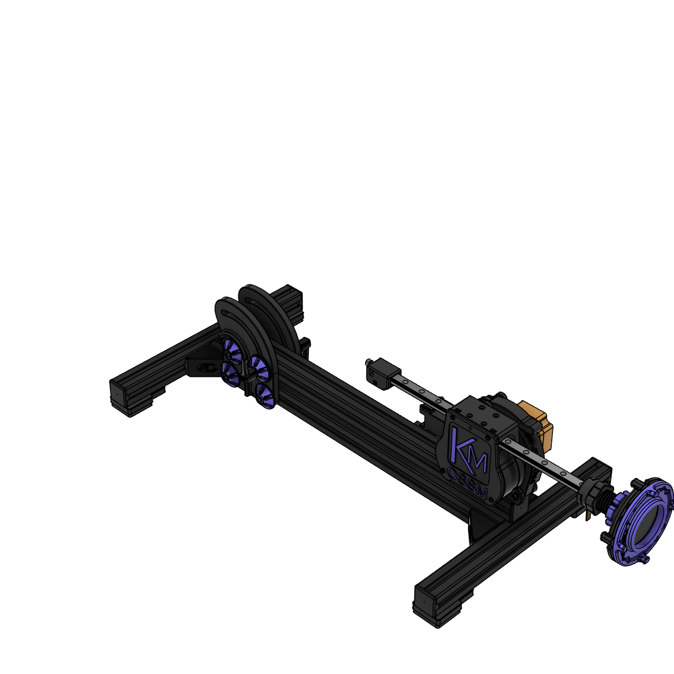
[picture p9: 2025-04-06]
Documentation/_images/Overview ALT - R2P - Folded.png

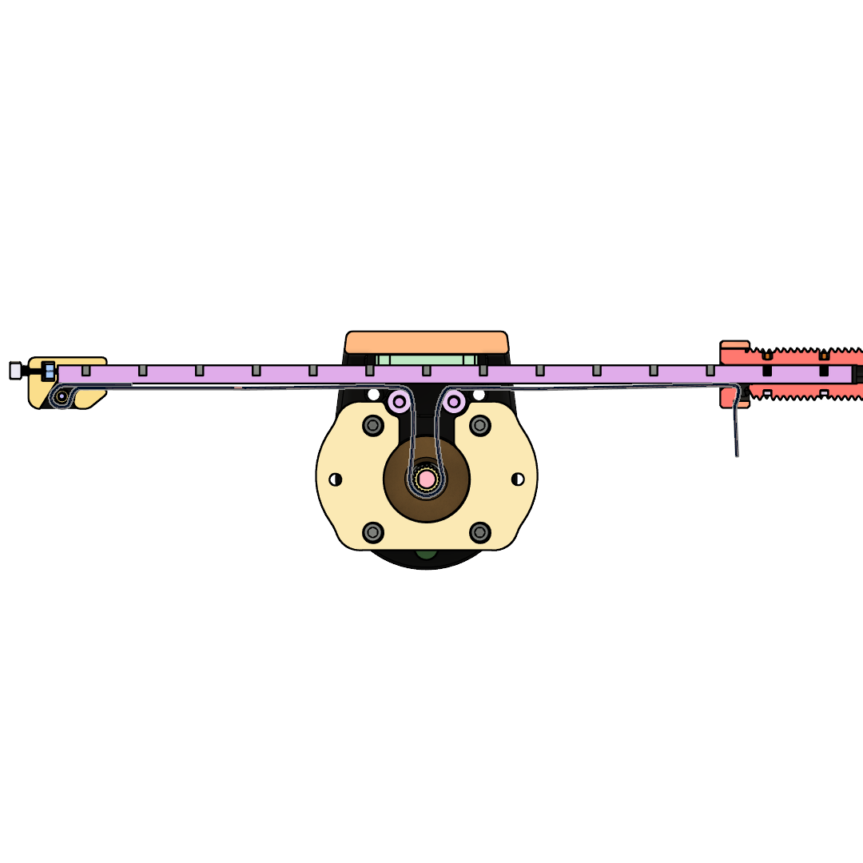
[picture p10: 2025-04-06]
Printed Parts/Actuator/_images/Cut View - Belt Routing Overview.png

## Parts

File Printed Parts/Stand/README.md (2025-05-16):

### Default base: [3030 Extrusion - Single Pivot Arm](#ossm---3030-extrusion-mount)

# OSSM - 3030 Extrusion Mount
<!-- ### [Bill Of Materials](3030%20Extrusion%20Base/BOM.md)   -->

### [Assembly Guide Videos](https://www.youtube.com/playlist?list=PLzSK7OAu3KNS-aOQfpv3f_BJH9GNdLJ7Q)

### Printing
**3030 Extrusion Mount Standard Print Settings:**  

    6 Walls
    Infill type: Cross Hatch (or gyroid) 25%
    Supports: None
 - **Filament estimate:** 246g
 - **Recommended filament:** PLA+
 - All parts are intended to print in the provided file default orientation. 

**Printed parts:**

    (Qty 1) Pivot Plate Left
    (Qty 1) Pivot Plate Right
    (Qty 8) Handle Spacer
    (Qty 4) Extrusion Foot
    (Qty 6) Extrusion Cap

<!-- ### [Additional Documentation](3030%20Extrusion%20Base/README.md)  -->

### Bill Of Materials
    (Qty 12) M6x12 Socket Cap Head Bolt
    (Qty  6) M6x25 Socket Cap Head Bolt
    (Qty  2) M6 Handle 25mm
    (Qty  6) M6 Washer
    (Qty 20) M6 T-Nut '3030'
    (Qty  4) 90 Degree '3030' Corner Bracket
    (Qty  2) 1.5" (38mm) Reinforced Rubber Washer
    (Qty  4) 1.5" (38mm) Square Non-Slip Furniture Pad
    (Qty  1) 20" (508mm) 3030 Extrusion
    (Qty  1) 18" (467mm) 3030 Extrusion
    (Qty  2) 14" (355mm) 3030 Extrusion
    (Recommended) Sandbag

## Legacy README  
The above BOM is accurate for a new Stand-only assembly. Actuator and PCB Mounting BOM can be found in [Mounting](/Printed%20Parts/Mounting/)

Legacy README retained for Stand assembly reference

    //TODO: Needs update for 57AIM30 Gold Motor & PitClamp Mini default build. 

You can view the 3D model at 
[OnShape link](https://cad.onshape.com/documents/d520ea9a8cadb4ae8681f59b/w/00b211a6fa3b76c59ef28f4e/e/5f2c80d9d9c2433a7be7f789)



<!-- ![image](https://github.com/KinkyMakers/OSSM-hardware/assets/12459679/68e3e564-df99-465a-8d91-f74ca8b0cc89) -->



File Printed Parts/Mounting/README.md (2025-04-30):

# Mounting

### Standard Actuator mounting base: [PitClamp Mini](#pitclamp-mini)

### Standard PCB mount: [PCB Enclosure](#pcb-enclosure)

# PitClamp Mini v1.1

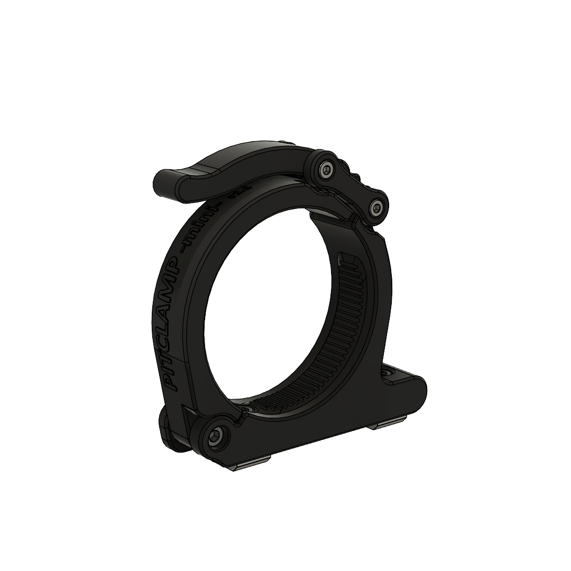
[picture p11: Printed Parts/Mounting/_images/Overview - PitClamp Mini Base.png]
Overview - PitClamp Mini
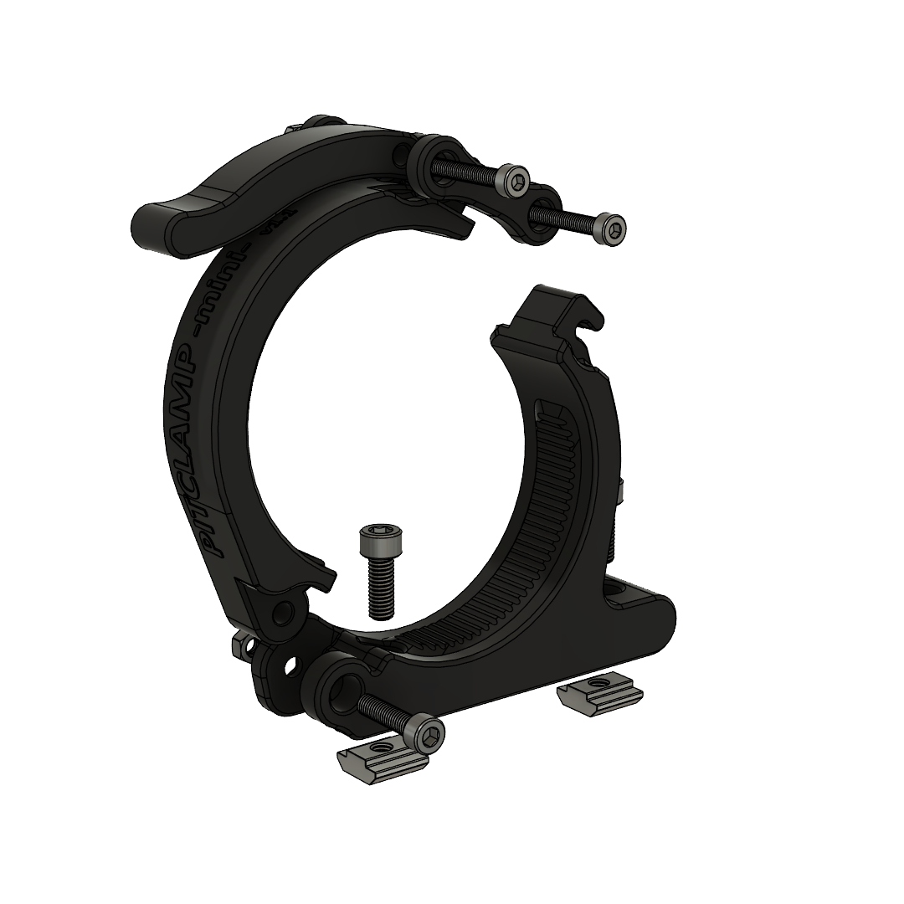
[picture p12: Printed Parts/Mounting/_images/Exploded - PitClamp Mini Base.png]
Exploded - PitClamp Mini
|  | 
| ---- | ---- |

**Developed by: armpit**

3d printed modular quick-release adjustable and removable mount ecosystem for 57AIM, 42AIM, iHSV57 NEMA23 motors.  
  - 4 degree precision quick-adjustable rotation
  - Motor can be quickly removed from mount for storage or use in another base  

Stress tested to 50 ft-lb without grip being compromised. (PLA 6 walls 10% infill)  

### Supported motors:  
| **57AIM** *(30/15/10)* | **47AIM** *(30/15/10)* | **iHSV57<sup>1</sup>** (180w<sup>2</sup>) |
| ---- | ---- | ---- |
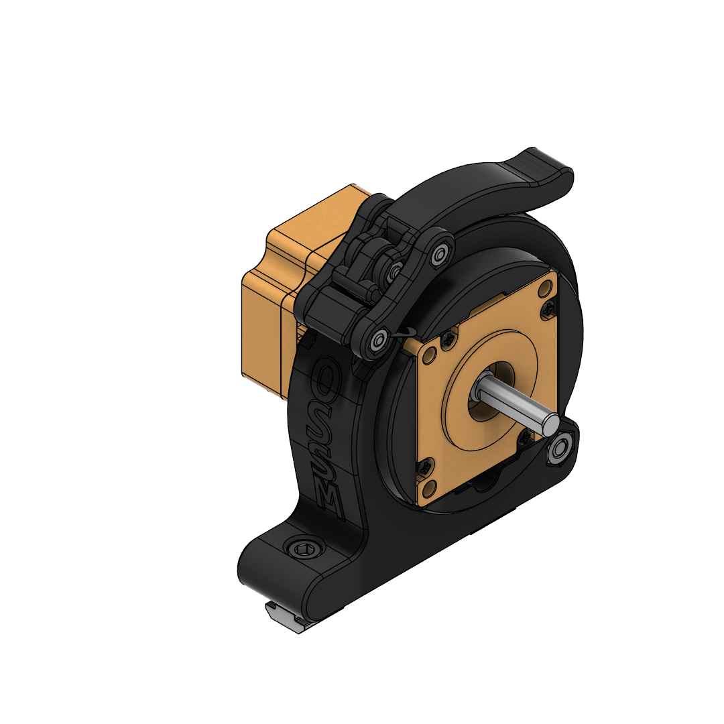
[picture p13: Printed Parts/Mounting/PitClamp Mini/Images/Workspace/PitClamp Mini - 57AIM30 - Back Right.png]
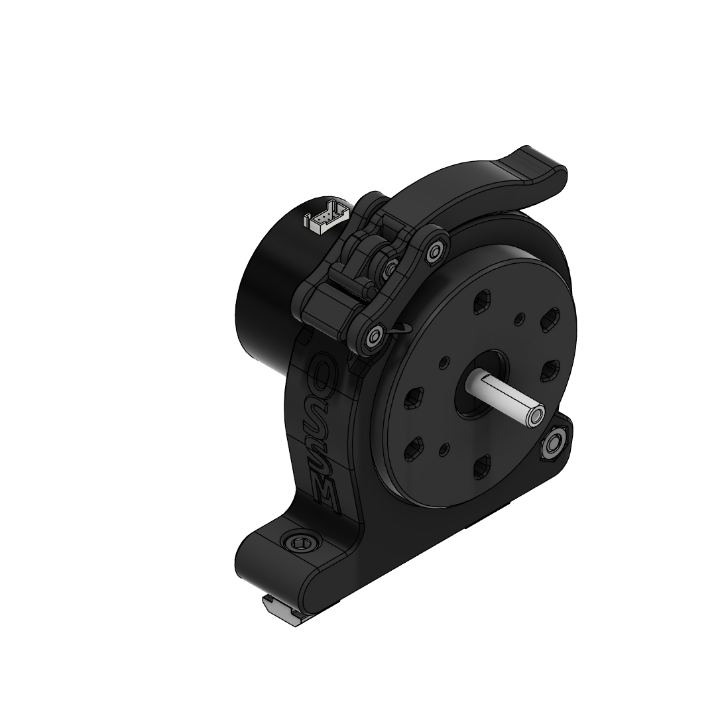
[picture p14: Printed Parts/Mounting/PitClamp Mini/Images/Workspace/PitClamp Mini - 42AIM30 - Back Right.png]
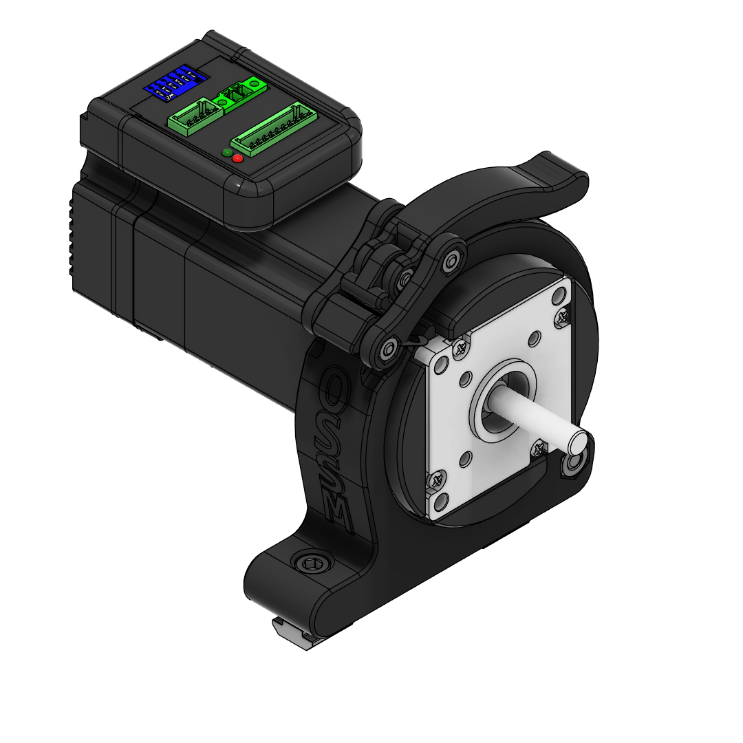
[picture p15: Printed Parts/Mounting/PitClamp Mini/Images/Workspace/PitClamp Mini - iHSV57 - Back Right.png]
 |  |  |
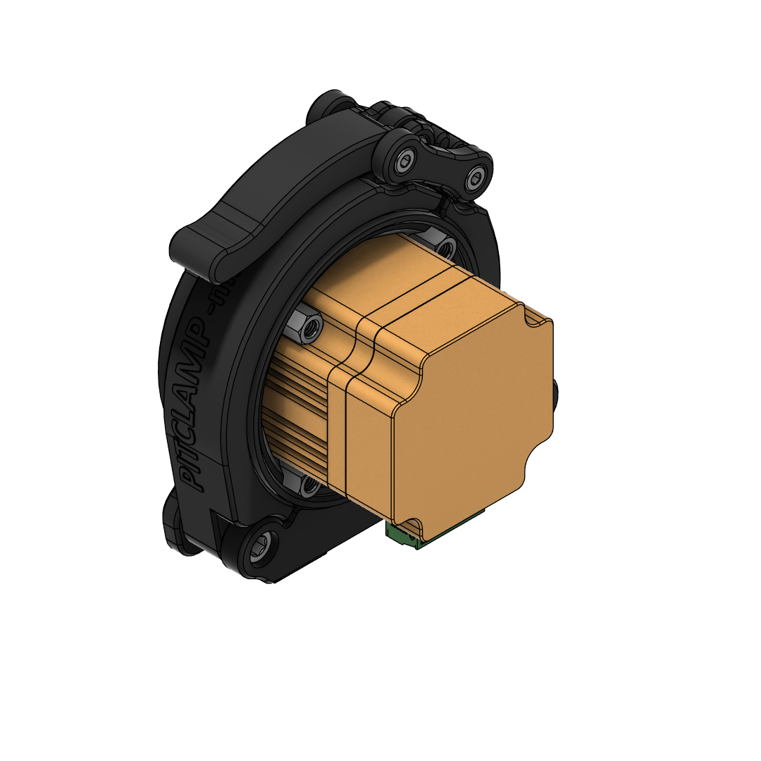
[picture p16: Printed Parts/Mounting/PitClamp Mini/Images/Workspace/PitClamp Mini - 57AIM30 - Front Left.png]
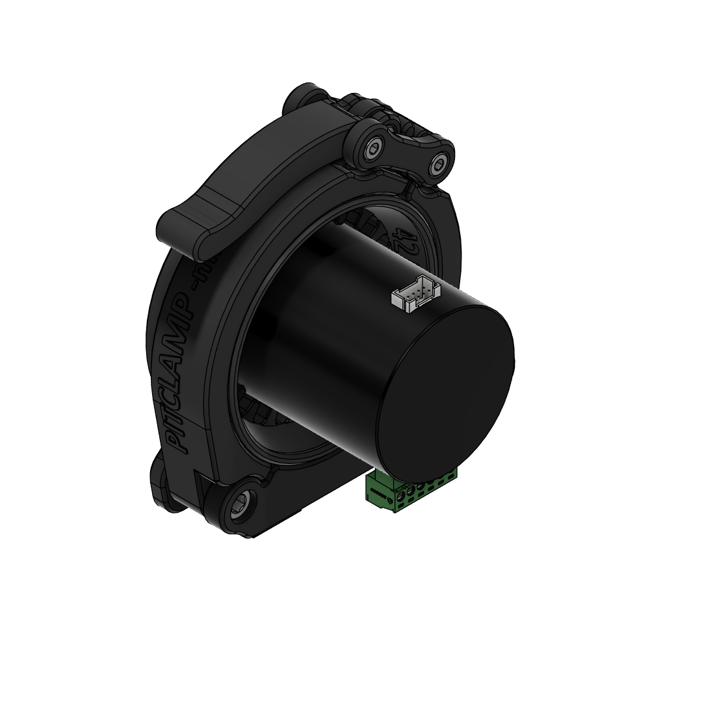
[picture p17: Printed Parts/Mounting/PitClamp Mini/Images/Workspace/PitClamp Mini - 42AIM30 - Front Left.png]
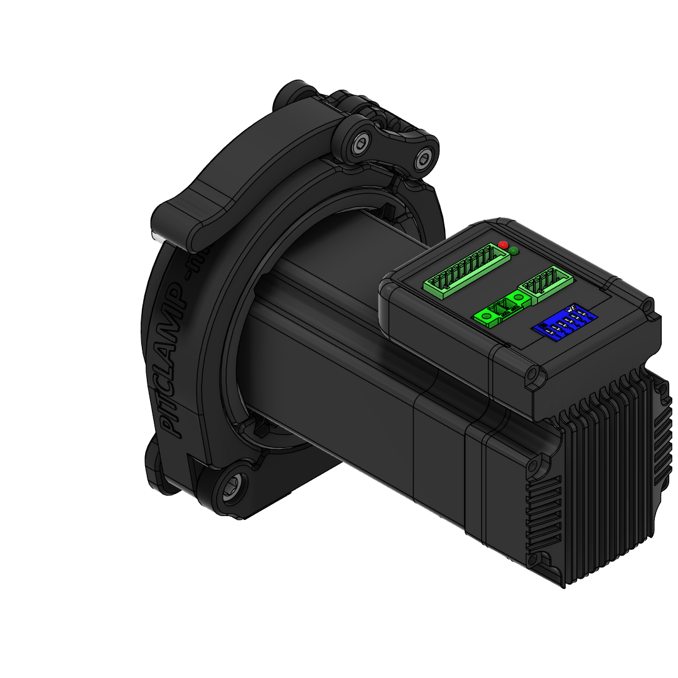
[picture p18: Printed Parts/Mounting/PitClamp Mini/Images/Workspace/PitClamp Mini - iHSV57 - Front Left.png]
|  |  |  |

<sup>1</sup>:The iHSV57 ring is two parts but snaps into two pieces after removing from printer. Clasp each half around the motor to assemble.  
<sup>2</sup>: Smaller than 180w iHSV57 will require modifications to that ring. 

### Printing
**PitClamp Mini Standard Print Settings:**  

    6 Walls
    Infill type: Cross Hatch (or gyroid) 10%
    Supports: Tree Supports with 5 degree threshold angle
    Seam: Nearest (or your personal preference)
 - **Filament estimate:** 150g
 - **Recommended filament:** PLA+
 - All parts are intended to print in the provided file default orientation. 
   - **Printing the Base components in other orientations will cause structural weakness**

**Printed parts:**

    (Qty 1) Mounting Ring - PitClamp Mini - 57AIM V1.1
    (Qty 1) Base - PitClamp Mini - Dogbone Bolts
    (Qty 1) Base - PitClamp Mini - Dogbone Nuts
    (Qty 1) Base - PitClamp Mini - Handle
    (Qty 1) Base - PitClamp Mini - Lower V1.1
    (Qty 1) Base - PitClamp Mini - Upper V1.1

If your printer is well calibrated and your material layer strength is optimal, the print-in-place Upper+Handle is recommended, found in the [/Non-Standard](Non-standard) folder.

### [Bill Of Materials](PitClamp%20Mini/BOM.md)  

### [Assembly Guide Videos](PitClamp%20Mini/ASSEMBLY_GUIDES.md)

### [Updates](PitClamp%20Mini/UPDATES.md) (Last updated - 03.06.2025)

### [Additional Documentation](PitClamp%20Mini/README.md) 



# PCB Enclosure

### Printing
**3030 Extrusion Mount Standard Print Settings:**  

    4 Walls
    Infill type: Cross Hatch (or gyroid) 10%
    Supports: None
 - **Filament estimate:** TODO
 - **Recommended filament:** PLA+
 - All parts are intended to print in the provided file default orientation. 

**Printed parts:**

    (Qty 1) PCB - Box
    (Qty 1) PCB - Lid

### Bill Of Materials
    (Qty 6) M3x8 Socket Cap Head Bolt (Longer okay)
    (Qty 2) M6x12 Socket Cap Head Bolt // Needs confirmation
    (Qty 2) M6 T-nuts

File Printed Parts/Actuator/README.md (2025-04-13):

# Actuator
<p align="center" >
    
</p>

## Printing
**Actuator Standard Print Settings:**  

    6 Walls
    Infill type: Cross Hatch (or gyroid) 15%
    Supports: None
 - **Filament estimate:** 200g
 - **Recommended filament:** PLA+
 - All parts are intended to print in the provided file default orientation. 
   - **Printing threaded components in other orientations will cause structural weakness**
     - For 24mm Clamping Thread, use 2 raft layers to promote better bed adhesion.
     - If you have issues with the 24mm Clamping Thread, use [Non-standard](Non-standard/) 24mm Thread and Belt Clamp files. 
       - (Qty 2) M3x8
       - (Qty 1) M3x16
       - (Qty 3) M3 Hex Nut

**Printed parts:**

    (Qty 1) Body - Bottom
    (Qty 1) Body - Middle
    (Qty 1) Body - Cover
    (Qty 1) Belt Tensioner
    (Qty 1) 24mm Clamping Thread - End Effector
    (Qty 1) 24mm Clamping Thread - Belt Clamp
    (Qty 2) 24mm Nut - 5 Sided

<!-- ### [Additional Documentation](3030%20Extrusion%20Base/README.md)  -->

## Bill Of Materials

### Default Actuator Hardware
**GT2 Pulley** 

    8mm Bore, 20 Tooth, 10mm Width
**GT2 Timing Belt** 

    10mm Width, 500mm length
**MGN12H Rail + Bearing Block**

    Minimum 250mm
    Suggested 350mm
    Maximum 550mm

Rail length = desired maximum stroke + 180mm  
Must be MGN**12H** rail.  
H is a longer bearing block than C for greater stability. 12 indicates 12mm rail width.

**Ball Bearings**

    (Qty 6) MR115-2RS 5x11x4mm 

**Fasteners**  

    (Qty 8) M3x8  Socket Cap Head Bolt 
    (Qty 2) M3x16 Socket Cap Head Bolt 
    (Qty 1) M3x20 Socket Cap Head Bolt 
    (Qty 7) M3 Hex Nut
    (Qty 3) M5x20 Socket Cap Head Bolt
    (Qty 1) M5 Hex Nut
    (Qty 4) M5x35 Socket Cap Head Bolt 
    (Qty 4) M5 20mm Hex Coupling Nut (Or M5 Hex Nut)

## Assembly


| |  |
| ---- | ---- |

(Click to enlarge)

### Belt Routing

| Tensioner | Body | Belt Clamp |
| ----- | ----- | ---- |
|  |  |  |

(Click to enlarge)

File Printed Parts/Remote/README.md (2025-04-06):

# OSSM - Remote

### Printing
**Remote Standard Print Settings:**  

    3 Walls
    Infill type: Cross Hatch (or gyroid) 25%
    Supports: Yes - Auto
 - **Filament estimate:** 70g

Additional knob choices are available in the [Non-standard](Non-standard/) directory

**Printed parts:**

    (Qty 1) Body
    (Qty 1) Top Cover
    (Qty 2) Knob

### Bill Of Materials
    (Qty 2) M4x6 Button Cap Bolt

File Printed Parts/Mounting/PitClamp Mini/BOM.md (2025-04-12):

# PitClamp Mini Bill Of Materials 

## Latching Mechanism:
    2x M4x25 Socket Cap Head Bolt
    1x M4x12 or M4x10 Socket Cap Head Bolt
    3x M4 Hex Nut
**Note:** Non-standard print-in-place Upper+Handle removes
  - 1x M4x12 or M4x10 Socket Cap Head Bolt
  - 1x M4 Hex Nut

## Bases:

####  Standard Base
    Rear Hinge:
      1x M5x20 Socket Cap Head Bolt
      1x M5 Hex Nut
    Attaching Base to Extrusion:
      2x M6x20 (M6x16 (or M6x15) for 3030 Extrusion) Socket Cap Head Bolt
      2x M6 T-Nut
<!--
####  Double Hinge Base
    Rear Hinge:
      1x M6x20 Socket Cap Head Bolt
      1x M6 Hex Nut
    Front Hinge:
      1x M6x20 Socket Cap Head Bolt
      1x M6 Hex Nut
    Attaching Base to Extrusion:
      2x M6x20 (M6x15 for 3030 Extrusion) Socket Cap Head Bolt
      2x M6 T-Nut

 ### (FUTURE, maybe) Side Mount Base
    For attaching to 3030 extrusion:
      2x M6x20 Socket Cap Head Bolt //TODO: Confirm that M6x25 is too long
      2x M6 T-Nut
    For attaching to 4040 extrusion:
      2x M6x25 Socket Cap Head Bolt
      2x M6 T-Nut -->

## Mounting Rings:

#### 57AIM 
    4x M5x35 Socket Cap Head Bolt 
    4x M5x20mm Hex Coupling Nuts OR M5 Hex Nuts

#### iHSV57
    4x M5x40 Socket Cap Head Bolt
    4x M5 Hex Nuts

#### 42AIM
    4x M3x16 Socket Cap Head Bolt
      (May vary by actuator body design)

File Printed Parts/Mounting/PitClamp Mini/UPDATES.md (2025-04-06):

A stream of updates made to PitClamp Mini

_Links may go bad, if a reference changes I am not keeping it updated in this file._

- 04.02.2025 - Misc improvements, v1.1 release 
  - Pivot bolt is now M5x20 ~~M6x20~~ 
  - Lower Dogbone grip slightly loosened
- 03.06.2025 - Official Release to OSSM Project
- 11.22.2024 - Added v1.1 57AIM Ring (Latest recommended default)
- 09.08.2024 - Refactored file structure.
- 09.08.2024 - Updated to new default files to simplify BOM. 
- 09.04.2024 - Added **Standard Base w/ Helper Brim** STEP file to [Files](/Files/) folder _(Helps prevent latch corner from lifting during print)_
- 09.03.2024 - Added **Ring Template** STEP files to [Ring Template](/Files/Ring%20Template/) folder
- 09.03.2024 - Added **Centered 42AIM Ring** to [Non-Standard Parts](/Files/Non-Standard%20Parts/) folder _(Compatibility with just_b's motor head)_
- 08.29.2024 - Added **57AIM Cable Passthru** Ring to [Non-Standard Parts](/Files/Non-Standard%20Parts/) folder _(Experimenting with motor head mounted Reference Board)_
- 08.28.2024 - Added **[Print-In-Place PitClamp Mini](/Files/Experimental/Print%20In%20Place/)** to [Experimental Parts](/Files/Experimental/) folder _(Reduced hardware)_
- 08.28.2024 - Revised **Extrusion Ring** from Normal to Experimental status _(Needs a stronger design for re-release)_

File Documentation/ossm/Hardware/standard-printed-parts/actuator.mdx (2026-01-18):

---
title: "Actuator Assembly"
description: "Print settings, bill of materials, and assembly instructions for the OSSM actuator"
---

<Frame>
  OSSM Actuator overview showing the assembled linear actuator
</Frame>

## Printing

Follow these print settings for optimal strength and durability.

### Print Settings

| Setting | Value |
| --- | ----- |
| Walls | 6 |
| Infill Type | Cross Hatch or Gyroid |
| Infill Percentage | 15% |
| Supports | None |
| Filament Estimate | 200g |
| Recommended Filament | PLA+ |

<Warning>
Print all parts in the default file orientation. Printing threaded components in other orientations causes structural weakness.
</Warning>

<Tip>
For the 24mm Clamping Thread, use 2 raft layers to promote better bed adhesion.
</Tip>

<Accordion title="Troubleshooting: 24mm Clamping Thread issues">
If you have issues printing the 24mm Clamping Thread, use the Non-standard 24mm Thread and Belt Clamp files instead (available in the source repository). These require additional hardware:

- (Qty 2) M3x8
- (Qty 1) M3x16
- (Qty 3) M3 Hex Nut
</Accordion>

### Printed Parts List

| Quantity | Part Name |
| --- | --- |
| 1 | Body - Bottom |
| 1 | Body - Middle |
| 1 | Body - Cover |
| 1 | Belt Tensioner |
| 1 | 24mm Clamping Thread - End Effector |
| 1 | 24mm Clamping Thread - Belt Clamp |
| 2 | 24mm Nut - 5 Sided |

<Note>
For additional documentation, see the [3030 Extrusion Stand guide](/ossm/Hardware/standard-printed-parts/stand).
</Note>

## Bill of Materials

### GT2 Pulley

| Specification | Value |
| --- | ----- |
| Bore | 8mm |
| Teeth | 20 |
| Width | 10mm |

### GT2 Timing Belt

| Specification | Value |
| --- | ----- |
| Width | 10mm |
| Length | 500mm |

### MGN12H Linear Rail + Bearing Block

| Specification | Value |
| --- | ----- |
| Minimum Length | 250mm |
| Suggested Length | 350mm |
| Maximum Length | 550mm |

<Info>
Calculate your rail length using this formula: **desired maximum stroke + 180mm**

You must use an MGN**12H** rail. The "H" designates a longer bearing block than "C" for greater stability. The "12" indicates a 12mm rail width.
</Info>

### Ball Bearings

| Quantity | Specification |
| --- | --- |
| 6 | MR115-2RS 5x11x4mm |

### Fasteners

| Quantity | Specification |
| --- | --- |
| 8 | M3x8 Socket Cap Head Bolt |
| 2 | M3x16 Socket Cap Head Bolt |
| 1 | M3x20 Socket Cap Head Bolt |
| 7 | M3 Hex Nut |
| 3 | M5x20 Socket Cap Head Bolt |
| 1 | M5 Hex Nut |
| 4 | M5x35 Socket Cap Head Bolt |
| 4 | M5 20mm Hex Coupling Nut (or M5 Hex Nut) |

## Assembly

<Frame caption="Animated exploded view of actuator assembly">
  Animated exploded view showing how actuator components fit together
</Frame>

<CardGroup cols={2}>
  <Card>
    <Frame caption="Exploded view - front angle">
      Exploded view of actuator from front angle
    </Frame>
  </Card>
  <Card>
    <Frame caption="Exploded view - alternate angle">
      Exploded view of actuator from alternate angle
    </Frame>
  </Card>
</CardGroup>

### Belt Routing

Route the GT2 timing belt through the actuator body following these reference images:

<CardGroup cols={3}>
  <Card title="Tensioner">
    <Frame>
      Cross-section showing belt routing through the rear tensioner
    </Frame>
  </Card>
  <Card title="Body">
    <Frame>
      Cross-section showing belt routing through the middle body section
    </Frame>
  </Card>
  <Card title="Belt Clamp">
    <Frame>
      Cross-section showing belt routing through the front belt clamp
    </Frame>
  </Card>
</CardGroup>

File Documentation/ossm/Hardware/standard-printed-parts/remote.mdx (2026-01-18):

---
title: "Remote Control"
description: "Print settings and bill of materials for the OSSM wireless remote control enclosure"
---

The OSSM remote control provides a convenient handheld interface for controlling your device. This guide covers the print settings and hardware you need to build the remote enclosure.

## Printed Parts

You need to print the following components:

| Part | Quantity |
|---|---|
| Body | 1 |
| Top Cover | 1 |
| Knob | 2 |

<Tip>
Additional knob designs are available in the Non-standard directory (in the source repository) if you prefer alternative styles.
</Tip>

## Print Settings

Use these settings for all remote parts:

| Setting | Value |
|---|---|
| Walls | 3 |
| Infill Type | Cross Hatch or Gyroid |
| Infill Percentage | 25% |
| Supports | Yes - Auto |

<Note>
Estimated filament usage is approximately **70g** for all parts.
</Note>

## Bill of Materials

| Item | Quantity |
|---|---|
| M4x6 Button Cap Bolt | 2 |

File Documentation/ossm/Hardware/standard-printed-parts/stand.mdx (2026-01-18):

---
title: "3030 Extrusion Stand"
description: "Build the default OSSM mounting stand using 3030 aluminum extrusion with a single pivot arm design"
---

The 3030 Extrusion Stand is the default mounting solution for your OSSM. This design uses aluminum extrusion for a sturdy, adjustable base with a single pivot arm that allows angle adjustment during use.

<CardGroup cols={2}>
  <Card title="Bill of Materials" icon="list-check" href="/ossm/Hardware/standard-printed-parts/pitclamp/BOM">
    Complete parts list for ordering components
  </Card>
  <Card title="Assembly Guide Videos" icon="video" href="https://www.youtube.com/playlist?list=PLzSK7OAu3KNS-aOQfpv3f_BJH9GNdLJ7Q">
    Step-by-step video walkthrough
  </Card>
</CardGroup>

## 3D printing the parts

Print all stand components using the settings below for optimal strength and durability.

### Print settings

| Setting | Value |
|---|---|
| Walls | 6 |
| Infill type | Cross Hatch or Gyroid |
| Infill percentage | 25% |
| Supports | None |
| Filament estimate | 246g |
| Recommended filament | PLA+ |

<Tip>
All parts are oriented correctly in the provided STL files. Print them in their default orientation without rotation.
</Tip>

### Required printed parts

| Part | Quantity |
|---|---|
| Pivot Plate Left | 1 |
| Pivot Plate Right | 1 |
| Handle Spacer | 8 |
| Extrusion Foot | 4 |
| Extrusion Cap | 6 |

## Bill of materials

### Hardware

| Part | Quantity |
|---|---|
| M6x12 Socket Cap Head Bolt | 12 |
| M6x25 Socket Cap Head Bolt | 6 |
| M6 Handle 25mm | 2 |
| M6 Washer | 6 |
| M6 T-Nut (3030 profile) | 20 |
| 90 Degree 3030 Corner Bracket | 4 |
| 1.5" (38mm) Reinforced Rubber Washer | 2 |
| 1.5" (38mm) Square Non-Slip Furniture Pad | 4 |

### Aluminum extrusion

| Length | Quantity |
|---|---|
| 20" (508mm) 3030 Extrusion | 1 |
| 18" (467mm) 3030 Extrusion | 1 |
| 14" (355mm) 3030 Extrusion | 2 |

<Note>
A sandbag is recommended to add weight and stability to the stand during operation.
</Note>

## Additional resources

<Card title="View 3D Model" icon="cube" href="https://cad.onshape.com/documents/d520ea9a8cadb4ae8681f59b/w/00b211a6fa3b76c59ef28f4e/e/5f2c80d9d9c2433a7be7f789">
  Explore the complete 3D model on OnShape
</Card>

<Info>
This BOM covers the stand assembly only. For actuator and PCB mounting hardware, see the [Mounting documentation](/ossm/Hardware/standard-printed-parts/pitclamp/README).
</Info>

<Warning>
This documentation is being updated for the 57AIM30 Gold Motor and PitClamp Mini default build configuration. Some details may change.
</Warning>

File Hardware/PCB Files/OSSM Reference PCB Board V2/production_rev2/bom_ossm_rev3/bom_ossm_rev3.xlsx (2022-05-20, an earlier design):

RefDes | Value | Name | Pattern | Quantity | NOTES
C1, C3, C8, C14, C16, C17, C18, C19, C20, C21, C22, C24 | 100nF | X5R or X7R/16V/0402 | CAP_0402 | 12
C2, C4, C5 | 10uF | X5R or X7R/10V/0603 | CAP_0603 | 3
C6 | 22pF | C0G or NP0/16V/0402 | CAP_0402 | 1
C7, C9, C13, C15, C23 | 1uF | X5R or X7R/10V/0402 | CAP_0402 | 5
C10 | 10uF | X5R or X7R/16V/0603 | CAP_0402 | 1
C11 | 10uF | X5R or X7R/50V/1206 | CAP_1206 | 1
C12 | 330uF/63V | EEU-FC1J331L | CAPR-5/13.5h22 | 1 | Mount horizontally
D1, D3, D4, D5 | B1100 | B1100-13-F | SMA | 4
D2 | ST1060 | ST1060 | TO-220FP-2 | 1 | Confirm orientation before soldering
D6 | POWER | BLUE LED 0805 | DIO_0805 | 1
D7, D8, D9 | PESD1CAN 215 | PESD1CAN 215 | SOT23 | 3
J1 | 24/36V IN | RAPC722X | RAPC722X | 1
J2 | SERVO POWER | WJ128V-5.0-2P | TB-1x2/5/11x9/Sc_H | 1
J3 | TYPE-C-31-M-12 | TYPE-C-31-M-12 | TYPE-C-31-M-12 | 1
J4 | RS232 | HDR-1x3/0.1 male/vertical | HDR-1x3 | 1
J5 | RJ45 | DS1128-06-S8B0P-X | DS1128-06-S8B0P-X | 1
J6 | 3V3 | HDR-1x4/0.1 male/vertical | HDR-1x4 | 1
J7 | GND | HDR-1x4/0.1 male/vertical | HDR-1x4 | 1
J8 | SERVO CONTROL | HDR-1x10 | HDR-1x10 | 1
J9 | GPIO | HDR-1x4/0.1 male/vertical | HDR-1x4 | 1
J10 | LIMIT SW1 | HDR-1x2 | HDR-1x2 | 1
J11 | LIMIT SW2 | HDR-1x2 | HDR-1x2 | 1
L1 | 10uH | WPN4020H100MT | VLS4012E | 1
M1 | ESP32-WROOM-32D | ESP32-WROOM-32D | ESP-WROOM-32 | 1
Q1, Q2, Q3, Q4, Q5 | BC817 | BC817 | SOT23 | 5
R1, R3, R4, R6, R8, R11, R13, R17, R18, R19, R22 | 10K | 1%/0402 | RES_0402 | 11
R2 | 54.9K | 1%/0402 | RES_0402 | 1
R5 | 39K | 1%/0603 | RES_0603 | 1
R7 | 1K | 1%/0603 | RES_0603 | 1
R9, R16 | 100R | 1%/0402 | RES_0402 | 2
R10, R20, R21, R23 | 220R | 1%/0402 | RES_0402 | 4
R12 | 47K | 1%/0402 | RES_0402 | 1
R14, R15 | 5.1K | 1%/0402 | RES_0402 | 2
R24 | 20K | 1%/0402 | RES_0402 | 1
S1, S2 |  | K2-1107ST-A4SW-06 | K2-1107ST-A4SW-06 | 2
U1 | ME6211C33 | ME6211C33M5G-N or RT9080-33GJ5 | SOT23-5 | 1
U2 | LMR14006 | LMR14006YDDCR | SOT23-6 | 1
U3 | CP2102 | CP2102-GMR | QFN-28/5x5x0.5 | 1
U4 | SP3232E | SP3232EEA-L/TR or MAX232ECPWR | SSOP-16 | 1
U5 | WS2813 | WS2813 | WS2813 | 1
U6 | CC6900SO-05A | CC6900SO-05A | SOIC-8/150mil | 1

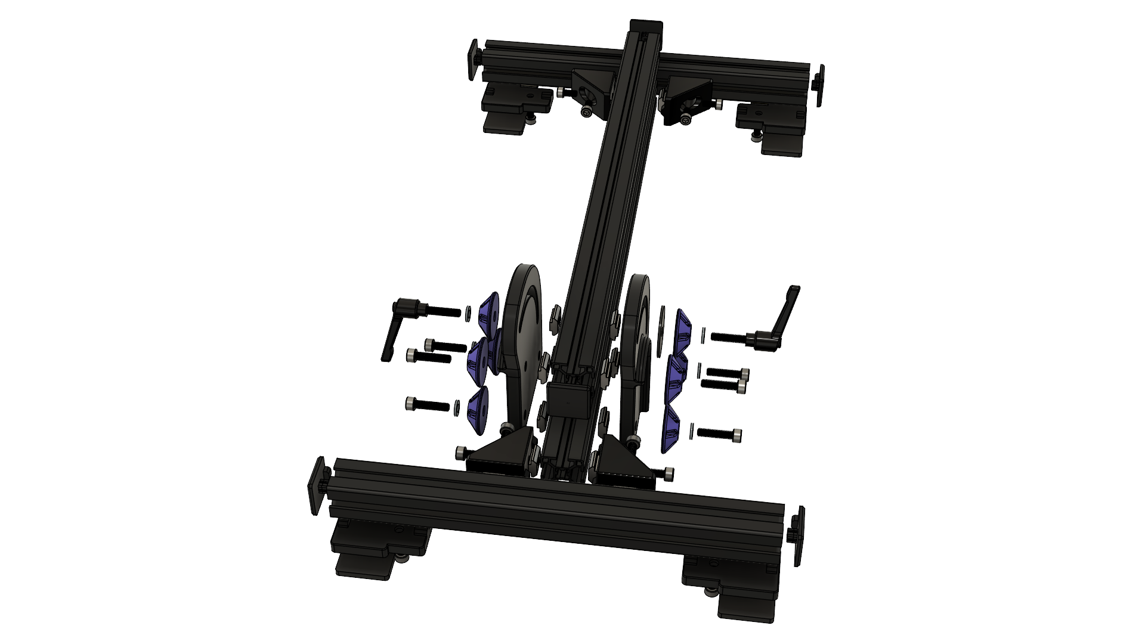
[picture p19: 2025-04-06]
Printed Parts/Stand/_images/Exploded ALT - Stand.png

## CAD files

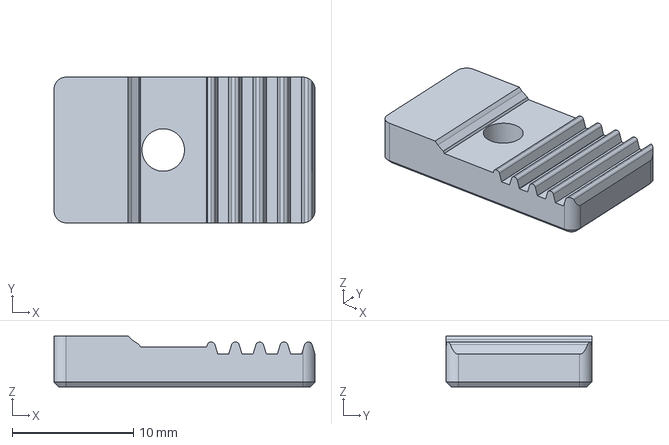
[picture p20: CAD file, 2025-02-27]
CAD Project/MAIN/RELEASE_02.27.2025/OSSM/Actuator/Linear Rail Assembly/Belt Clamp/OSSM - Actuator - Linear Rail Assembly - Belt Clamp - Top.stp
21.5 x 12.0 x 4.20 mm

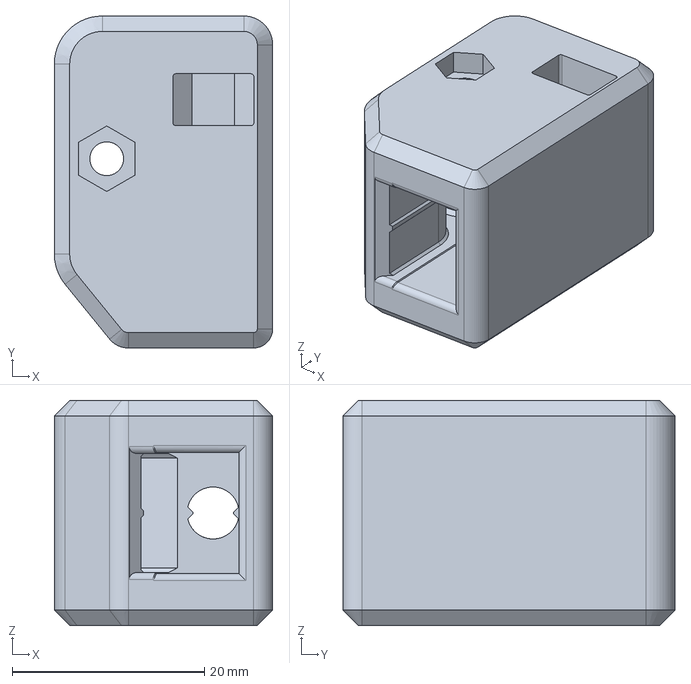
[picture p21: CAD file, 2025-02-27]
CAD Project/MAIN/RELEASE_02.27.2025/OSSM/Actuator/Linear Rail Assembly/Belt Tensioner/OSSM - Actuator - Linear Rail Assembly - Belt Tensioner - Open Back.stp
22.7 x 34.5 x 23.4 mm

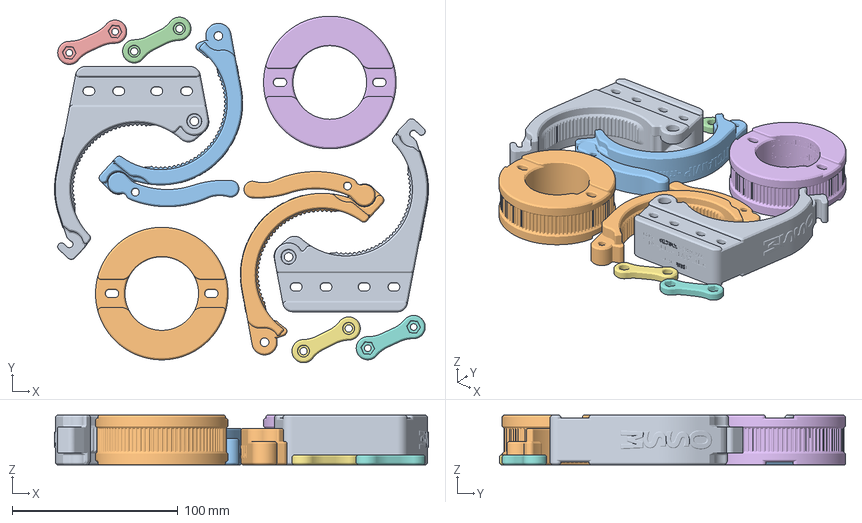
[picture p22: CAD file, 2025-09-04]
Printed Parts/OSSM Mods/PitClamp Mini Reinforced 3030 Hinges/Preconfigured 3mf/[Generic_3mf] 2x - PitClamp Mini v1.1 - Reinforced 3030 Hinge Complete.3mf
225.9 x 209.2 x 30.0 mm
OSSM - Base - PitClamp Mini - Lower V1.1 - Reinforced SideMount 3030.stl x 2
OSSM - Mounting Ring - PitClamp Mini - Extrusion Reinforced.stl x 2
OSSM - Base - PitClamp Mini - Upper V1.1 + Handle (Print In Place).stp x 2
OSSM - Base - PitClamp Mini - Dogbone Bolts.stp x 2
OSSM - Base - PitClamp Mini - Dogbone Nuts.stp x 2

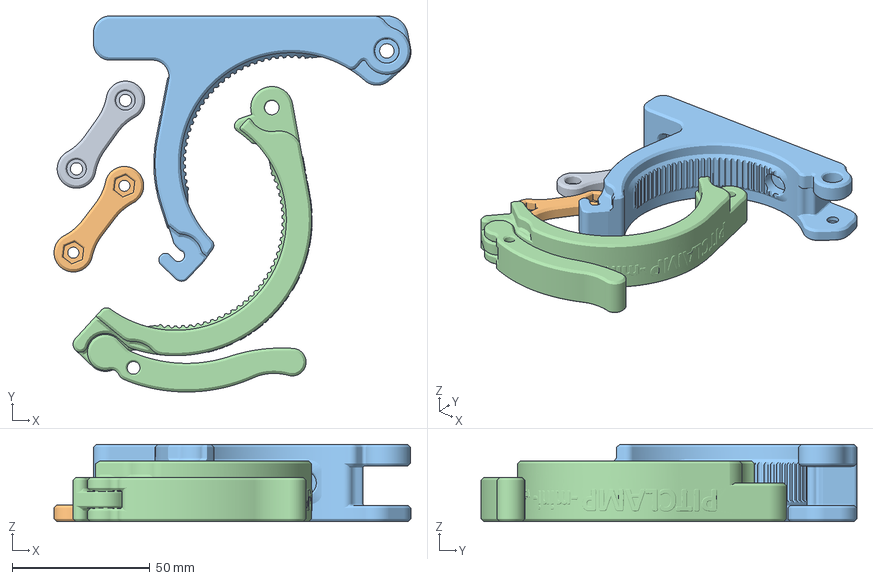
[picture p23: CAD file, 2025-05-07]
Printed Parts/OSSM Mods/PitClamp Mini Reinforced Standard/Preconfigured 3mf/[BBL_P1S] PitClamp Mini v1.1 - Reinforced Standard Complete.3mf
129.4 x 136.3 x 28.0 mm
OSSM - Base - PitClamp Mini - Dogbone Bolts.stp
OSSM - Base - PitClamp Mini - Dogbone Nuts.stp
OSSM - Base - PitClamp Mini - Lower V1.1 - Reinforced.stp
OSSM - Base - PitClamp Mini - Upper V1.1 + Handle (Print In Place).stp

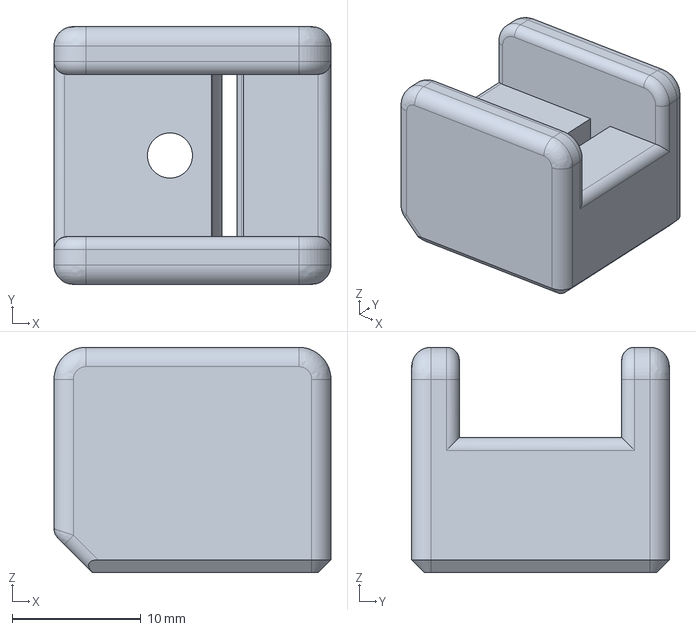
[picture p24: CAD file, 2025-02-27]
CAD Project/MAIN/RELEASE_02.27.2025/OSSM/Actuator/Linear Rail Assembly/Belt Clamp/OSSM - Actuator - Linear Rail Assembly - Belt Clamp - Bottom.stp
21.5 x 20.0 x 17.5 mm

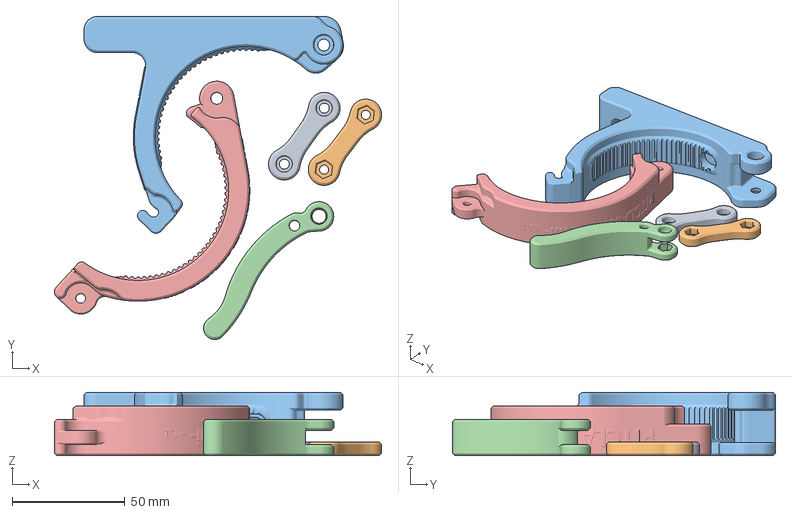
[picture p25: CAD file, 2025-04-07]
Printed Parts/OSSM Mods/PitClamp Mini Reinforced Standard/Preconfigured 3mf/[BBL_A1] PitClamp Mini v1.1 - Reinforced Standard Complete.3mf
145.1 x 143.2 x 28.0 mm
OSSM - Base - PitClamp Mini - Dogbone Bolts.stp
OSSM - Base - PitClamp Mini - Dogbone Nuts.stp
OSSM - Base - PitClamp Mini - Lower V1.1 - Reinforced.stp
OSSM - Base - PitClamp Mini - Handle.stp
OSSM - Base - PitClamp Mini - Upper V1.1.stp

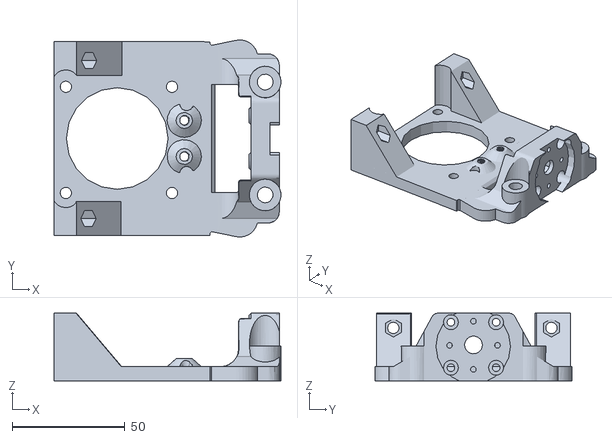
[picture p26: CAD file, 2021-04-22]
Hardware/OSSM Mounting/Emma's Mod - Adjustable mount for long Nema23 motor/ossm_nema23_60t_mainbody_V4.stl
100.5 x 87.2 x 30.0

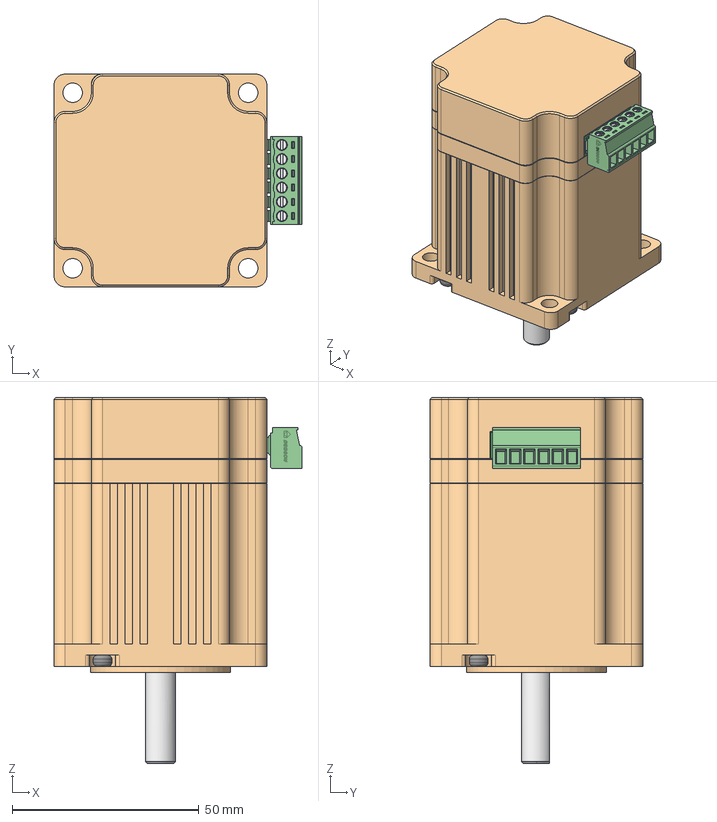
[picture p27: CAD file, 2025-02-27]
CAD Project/MAIN/RELEASE_02.27.2025/Assets/Motor/Assets - Motor - 57AIM30.stp
66.4 x 57.0 x 98.0 mm

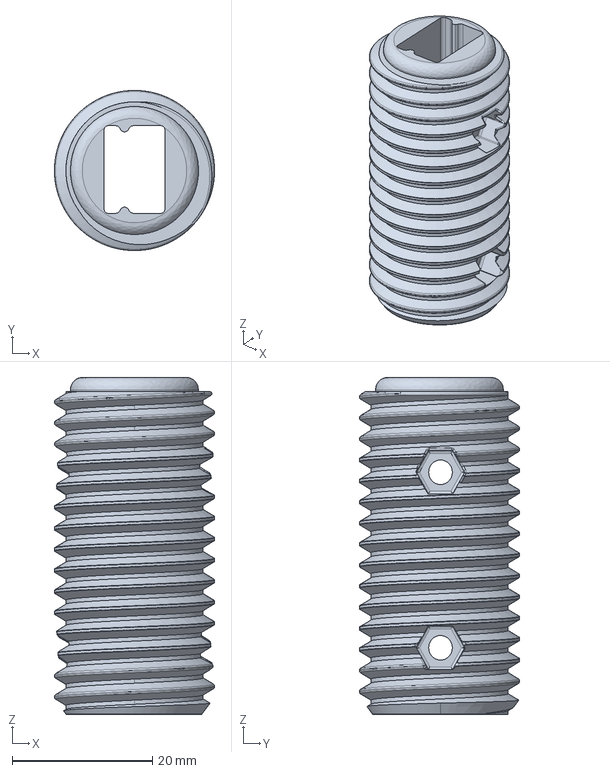
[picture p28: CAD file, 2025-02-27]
CAD Project/MAIN/RELEASE_02.27.2025/OSSM/Actuator/End Effector/24mm Thread/OSSM - Actuator - End Effector - 24mm Thread - 24mm Thread.stp
22.8 x 22.8 x 48.0 mm

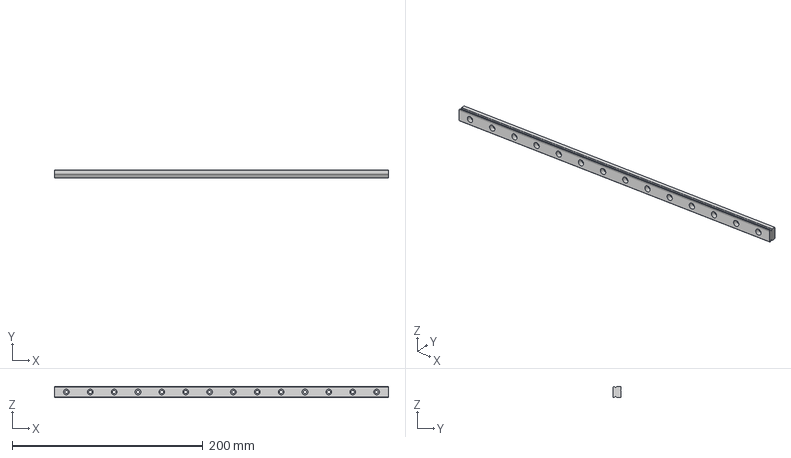
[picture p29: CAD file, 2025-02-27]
CAD Project/MAIN/RELEASE_02.27.2025/OSSM/Actuator/Linear Rail Assembly/Hardware/MGN12H 350MM.stp
350.0 x 8.00 x 12.0 mm

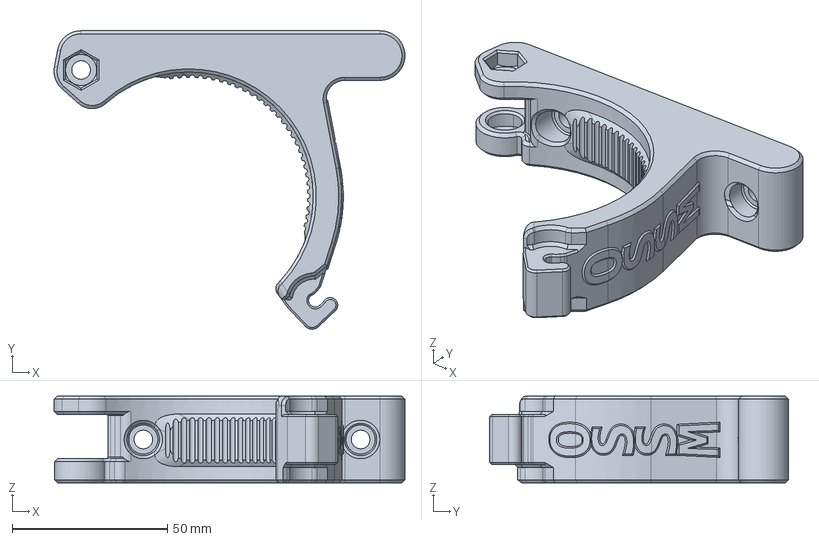
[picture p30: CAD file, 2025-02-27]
CAD Project/MAIN/RELEASE_02.27.2025/OSSM/Base/PitClamp Mini/OSSM - Base - PitClamp Mini - Lower.stp
113.1 x 96.2 x 28.0 mm

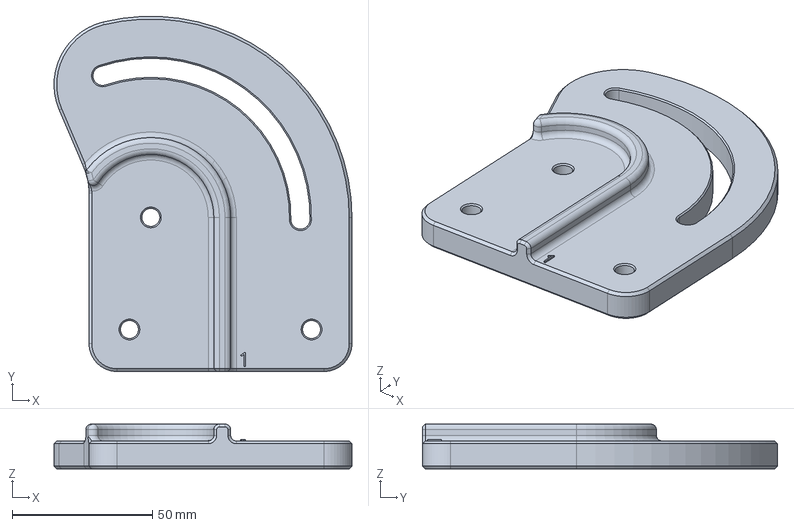
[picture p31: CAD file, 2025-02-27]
CAD Project/MAIN/RELEASE_02.27.2025/OSSM/Stand/3030 Extrusion Base Default/OSSM - Stand - 3030 Extrusion Base Default - Pivot Plate Right.stp
106.4 x 126.7 x 16.0 mm

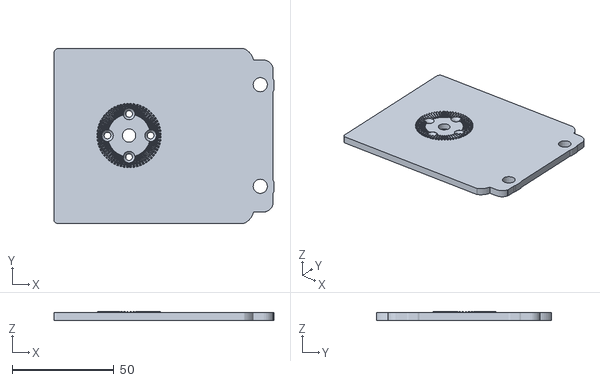
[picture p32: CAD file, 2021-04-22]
Hardware/OSSM Mounting/Emma's Mod - Adjustable mount for long Nema23 motor/ossm_nema23_60t_topcover_rosette_plate_V4.stl
108.2 x 86.0 x 4.40

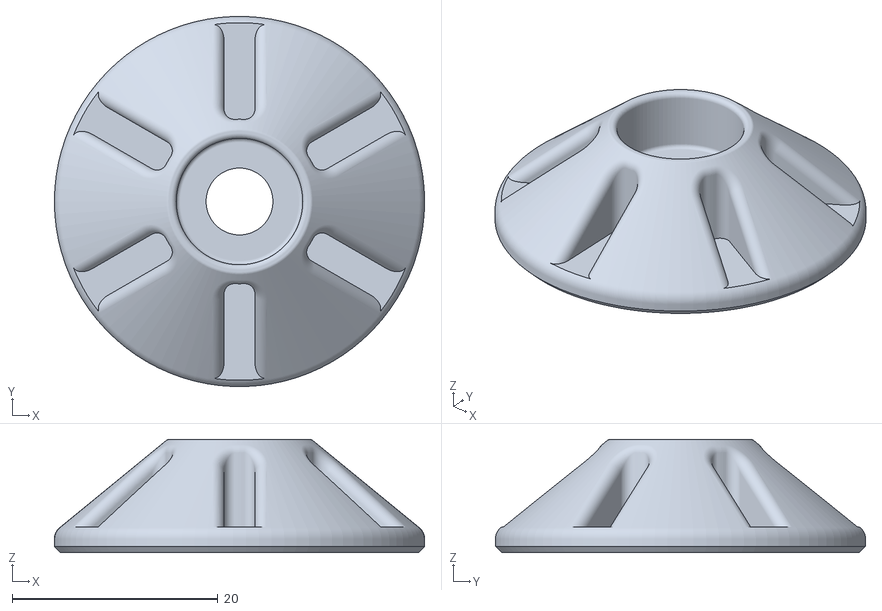
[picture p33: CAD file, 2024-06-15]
Hardware/OSSM Mounting/OSSM - Basic Mount/OSSM - Extrusion Mount - Spacer - 5mm.stl
36.0 x 36.0 x 11.0

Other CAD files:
Hardware/OSSM Mounting/OSSM - Basic Mount/Source Files/OSSM - Basic Mount - Side 1.step
Hardware/OSSM Mounting/OSSM - Full Extrusion Mount/OSSM - Extrusion Mount - Pivot Plate 1.stl
Hardware/OSSM Mounting/Shicks 4040 mount/aluxprofile/legs_store.stl
Hardware/OSSM Mounting/Shicks 4040 mount/STL Files/hinge-plate.stl
CAD Project/MAIN/RELEASE_02.27.2025/Assets/Motor/Assets - Motor - 57AIM30.f3d
CAD Project/MAIN/RELEASE_02.27.2025/OSSM/Actuator/Body/Bottom/Hardware/5x11x4 Bearing.f3d
CAD Project/MAIN/RELEASE_02.27.2025/OSSM/Actuator/Body/Bottom/Hardware/5x11x4 Bearing.stp
CAD Project/MAIN/RELEASE_02.27.2025/OSSM/Actuator/Body/Bottom/Hardware/M3 Nut.f3d
CAD Project/MAIN/RELEASE_02.27.2025/OSSM/Actuator/Body/Bottom/Hardware/M3 Nut.stp
CAD Project/MAIN/RELEASE_02.27.2025/OSSM/Actuator/Body/Bottom/Hardware/M3 x 8 Cap Head Screw.f3d
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

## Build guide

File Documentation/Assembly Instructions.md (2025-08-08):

# Assembly Instructions

#### _Note: This file is a work in progress migration of legacy documentation and may contain outdated information or parts_

## Open Source Sex Machine

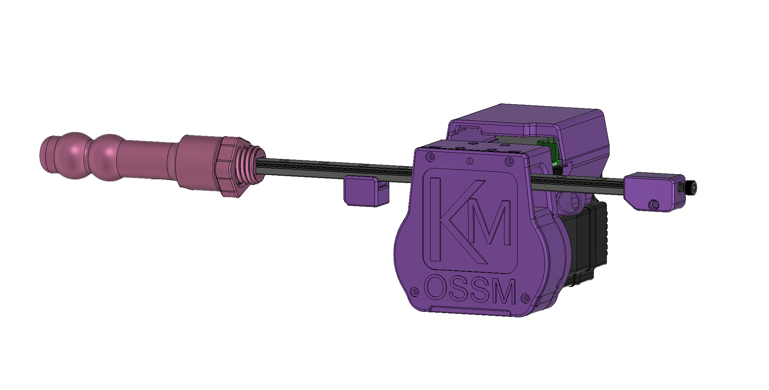
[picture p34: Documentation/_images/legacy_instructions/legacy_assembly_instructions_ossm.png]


Assembly Guide

### Table of Contents

* [Some comments on Safety](<Assembly Instructions.md#some-comments-on-safety>)
* [Parts Checklist](<Assembly Instructions.md#parts-checklist>)
  * [Purchased Parts](<Assembly Instructions.md#purchased-parts>)
  * [Printed Parts](<Assembly Instructions.md#printed-parts>)
* [Assembly Instructions](<Assembly Instructions.md#assembly-instructions>)
  * [Mate the Base Plate with the Motor](<Assembly Instructions.md#mate-the-base-plate-with-the-motor>)
  * [Build up the belt idler bearings](<Assembly Instructions.md#build-up-the-belt-idler-bearings>)
  * [Install and Align the Pulley](<Assembly Instructions.md#install-and-align-the-pulley>)
  * [Linear Rail Installation](<Assembly Instructions.md#linear-rail-installation>)
  * [Alternate Middle – Pivot](<Assembly Instructions.md#alternate-middle--pivot>)
  * [Belt Placement](<Assembly Instructions.md#belt-placement>)
  * [Belt Tensioner](<Assembly Instructions.md#belt-tensioner>)
  * [Wrap Belt Around Pulley](<Assembly Instructions.md#wrap-belt-around-pulley>)
  * [Belt Clamp](<Assembly Instructions.md#belt-clamp>)

## Some comments on Safety

### General Safety

* We’ve worked to make building an OSSM easy and not require expert level knowledge. With that said, only you can be responsible for your safety. If you are unsure about something, find a resource, ask the discord, or just pause for a minute before rushing into it. This is a DIY project, and everyone’s build is a bit different – so make sure you are comfortable with your setup and understand how it works!

### Electrical Safety

* 24V is generally considered a fairly safe, low voltage, but always be careful to check wiring polarity and make sure nothing conductive is near the board or power supply that could cause a short circuit.

### Mechanical Safety

* There are some pinch points in the OSSM near the rail – keep sensitive bits away from that during use!
* Depending on your motor selection, the OSSM can generate quite a bit of force, and that can hurt if it’s not applied in the right way, especially in delicate orifices! Always be able to move away from the machine if needed, or have someone specifically responsible for your safety if using it with a partner. Everyone has their own level or risk tolerance, so make sure you understand how your setup works, and give consideration to what you would do should something go wrong.

\
\
This is an open-source, community based project. Lots of people contribute to its success which is a huge strength for developing quickly! It also means we are not responsible for the complete safety of the design. Play risk-aware and consensually!\

## Parts Checklist

The Github list is always to be considered to be more up-to-date than this document, if there are discrepancies please visit the Discord and ask for clarification in #OSSM

This guide is for the complete OFFICAL OSSM, however there are many modifications that you may choose to make for your specific build.

### Purchased Parts

| | |
| --- | --- |
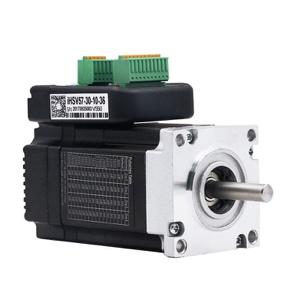
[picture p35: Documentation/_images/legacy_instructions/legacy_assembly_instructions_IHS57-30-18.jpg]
| **Nema 23 Servo Motor – IHSV57-30-18** Most people choose the 180W model for max power. 140 and 100w are also available. Avoid the _StepperOnline_ version because of compatibility issues |  |
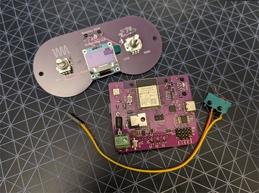
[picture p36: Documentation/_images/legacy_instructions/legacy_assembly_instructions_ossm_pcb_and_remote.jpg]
| **OSSM PCB & Remote** |  |
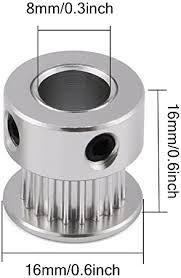
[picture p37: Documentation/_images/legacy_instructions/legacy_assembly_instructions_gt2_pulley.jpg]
| **GT2 Pulley – 20 Tooth, 8mm Bore, 10mm belt** |  |
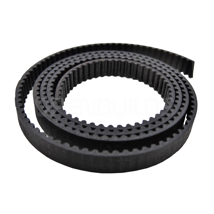
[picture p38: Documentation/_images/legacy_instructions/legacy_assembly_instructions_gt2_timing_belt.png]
| **GT2 Timing Belt – 10mm Width x 500mm length** Get a bulk amount of belt 500mm is a minimum for a standard build |  |
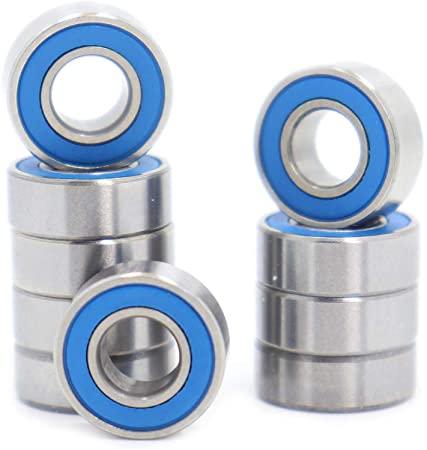
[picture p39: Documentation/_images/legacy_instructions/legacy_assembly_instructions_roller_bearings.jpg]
| **Roller Bearings MR115 – 5x11x4mm (Qty:6)** |  |
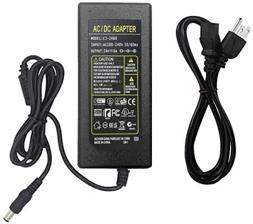
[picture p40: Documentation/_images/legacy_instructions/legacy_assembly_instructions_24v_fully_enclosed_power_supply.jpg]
| **24v 5A fully enclosed power supply** Look for one that is certified for use in your country |  |
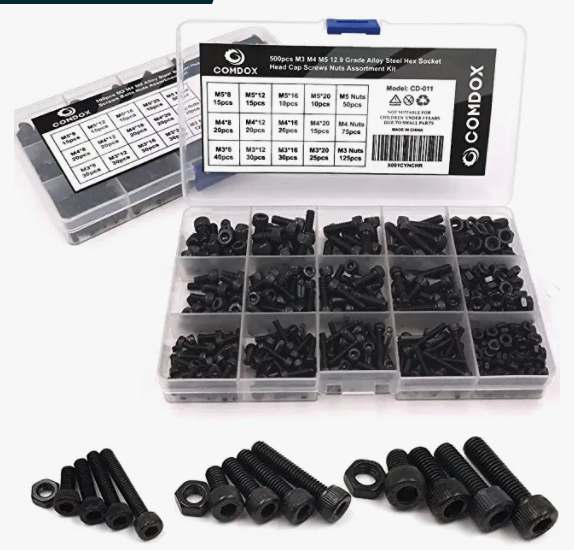
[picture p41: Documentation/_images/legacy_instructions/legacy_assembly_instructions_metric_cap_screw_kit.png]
| Metric Cap Screw Kit Should be about $20 USD, M5, M4, and M3 are used in the build in various lengths Most M5 cap head screws are 20/25mm long The Middle Pivot mount requires 4x m5x35 screws |  |
| | |

### Printed Parts

| | |
| :---: | --- |
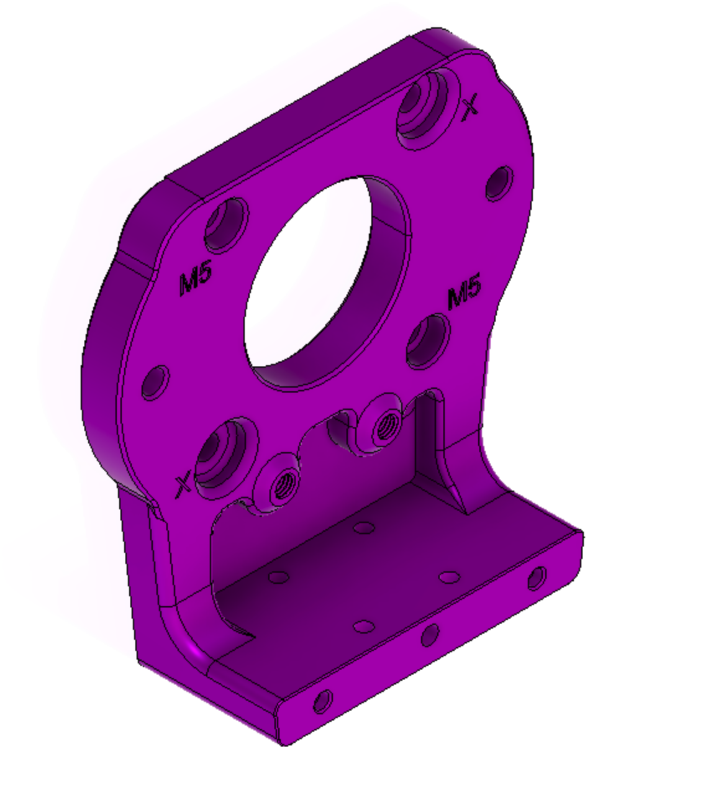
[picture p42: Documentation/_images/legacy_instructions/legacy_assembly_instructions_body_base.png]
| **Body - Base** |  |
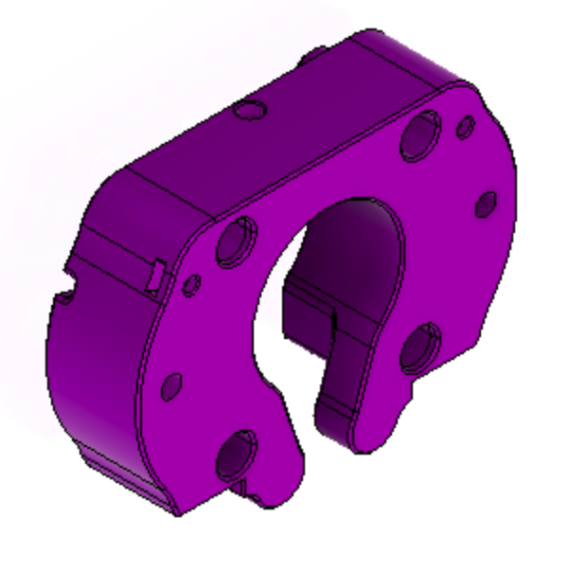
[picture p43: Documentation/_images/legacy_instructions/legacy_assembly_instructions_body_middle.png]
| **Body - Middle** |  |
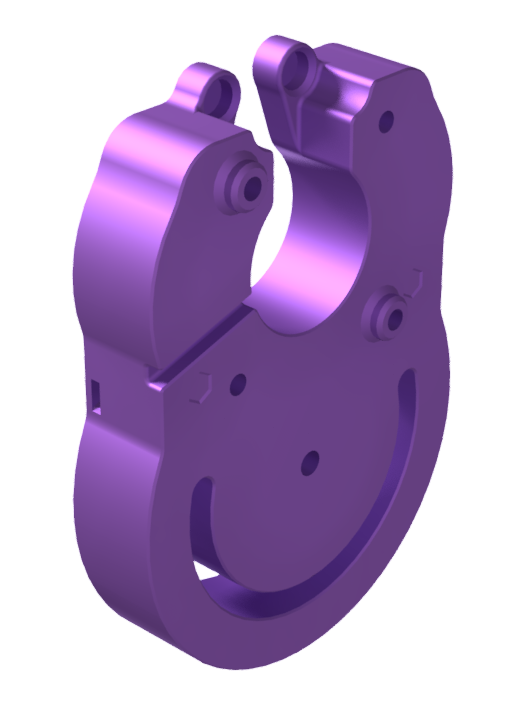
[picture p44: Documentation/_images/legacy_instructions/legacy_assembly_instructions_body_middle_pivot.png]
| **Body – Middle Pivot (Use instead for more mounting options)** |  |
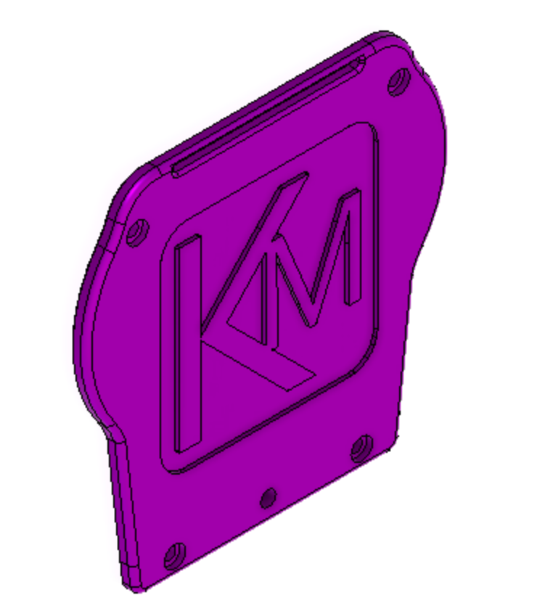
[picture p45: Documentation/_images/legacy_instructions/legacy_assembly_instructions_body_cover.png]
| **Body - Cover** |  |
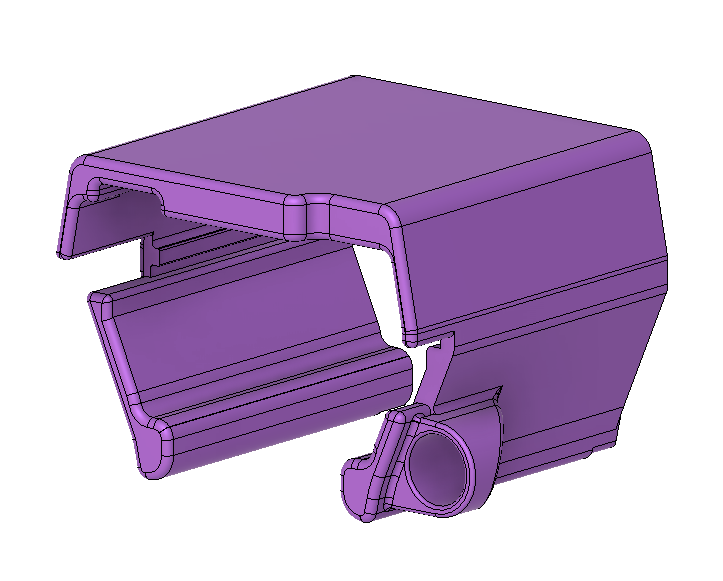
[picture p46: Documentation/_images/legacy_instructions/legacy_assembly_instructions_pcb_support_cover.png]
| **Body - PCB Support Cover** |  |
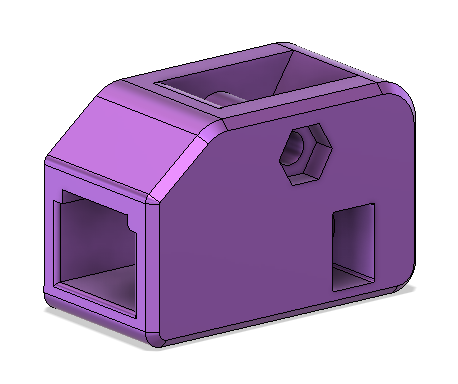
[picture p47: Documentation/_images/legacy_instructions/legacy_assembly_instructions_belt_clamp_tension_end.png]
| **Belt Clamp – Tensioner end** |  |
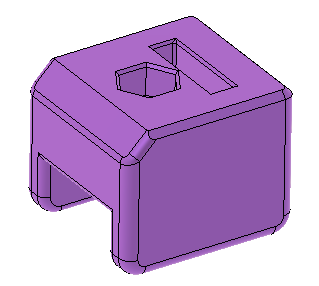
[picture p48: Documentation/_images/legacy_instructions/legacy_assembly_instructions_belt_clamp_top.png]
| **Belt Clamp - Top** |  |
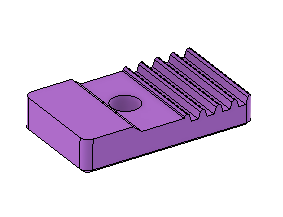
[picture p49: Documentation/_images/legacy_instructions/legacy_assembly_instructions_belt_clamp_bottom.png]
| **Belt Clamp - Bottom** |  |
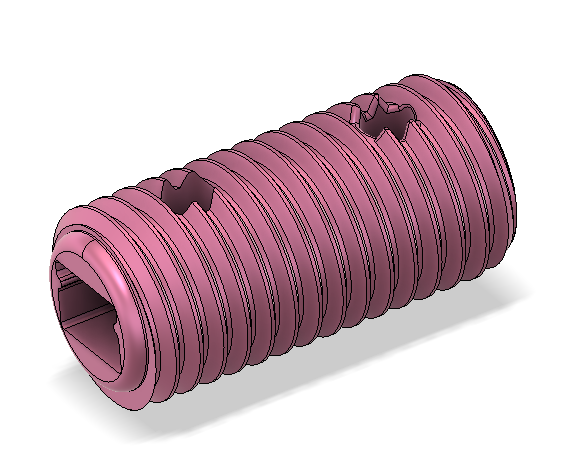
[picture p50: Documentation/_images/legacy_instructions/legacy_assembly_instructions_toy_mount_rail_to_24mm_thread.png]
| **Toy Mount – Rail to 24mm thread** |  |
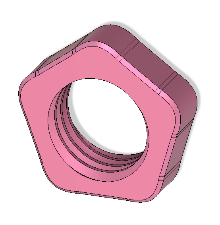
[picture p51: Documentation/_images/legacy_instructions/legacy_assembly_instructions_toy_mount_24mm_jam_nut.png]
| **Toy Mount - 24MM Jam Nut** |  |
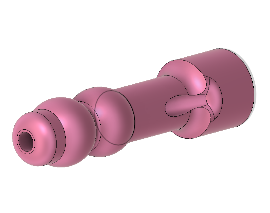
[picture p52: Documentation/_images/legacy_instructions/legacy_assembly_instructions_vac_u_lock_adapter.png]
| **Toy Mount - Vac-u-lock adapter (double double)** |  |
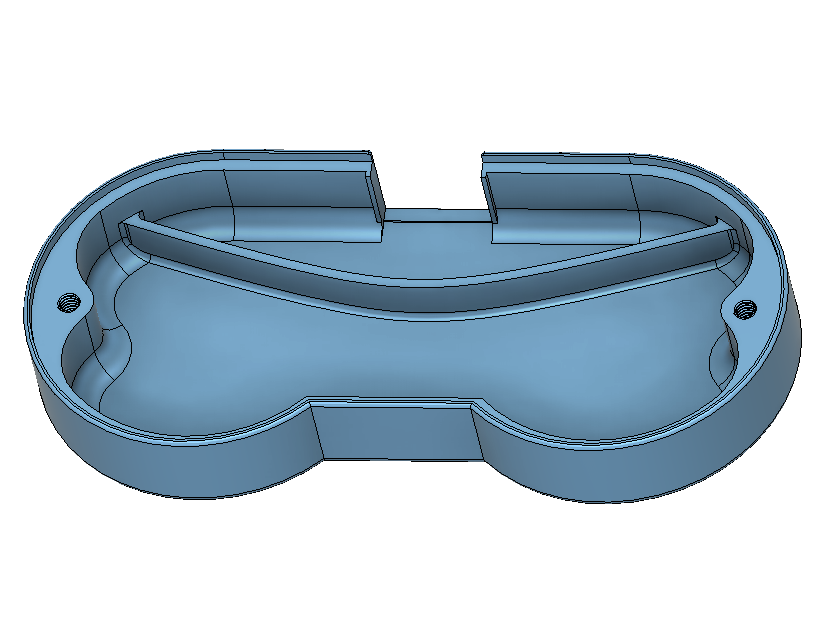
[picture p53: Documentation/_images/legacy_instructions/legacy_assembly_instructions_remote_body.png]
| **Remote Body** |  |
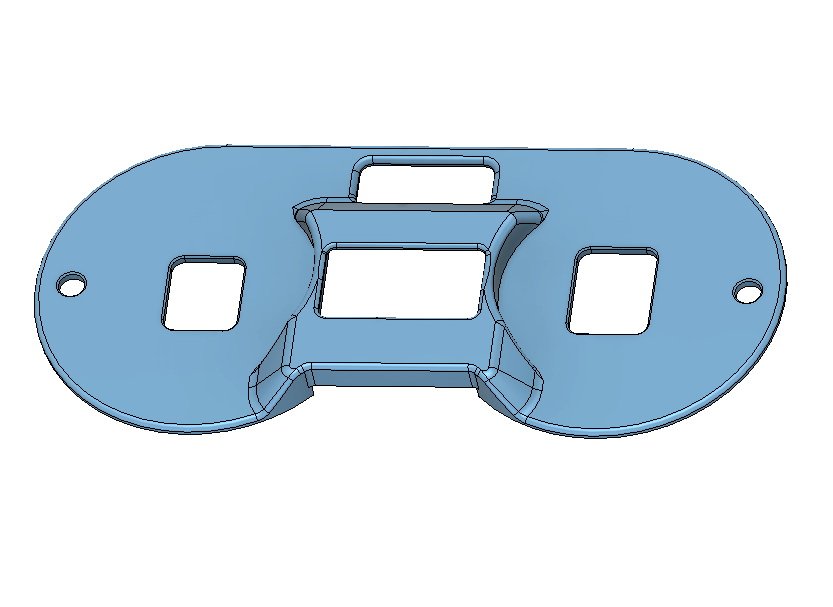
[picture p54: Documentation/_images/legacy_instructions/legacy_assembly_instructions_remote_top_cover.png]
| **Remote Top Cover** |  |
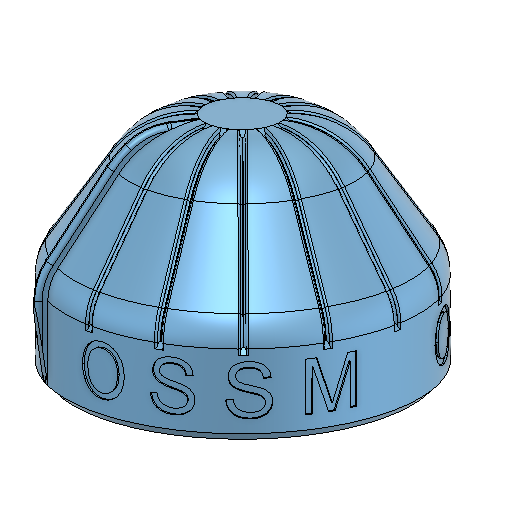
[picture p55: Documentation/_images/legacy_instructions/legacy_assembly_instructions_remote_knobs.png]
| **Remote Knobs x 2** |  |
| | |

\
\
\

## Assembly Instructions

\

### General Assembly Comments

#### Threadlocker

Recommend you use some form of threadlocker/Loctite on the fasteners going into metal (nuts of bearing) to prevent them from loosening as the ossm gets shaken around quite a bit.

If you do not have Loctite, some plain white glue does a decent job, just a small amount on the ends of the threads is all you need.

You can also put threadlocker on the motor shaft to help keep the pulley tightly in place – just be sure you are happy with it’s position, this can be very hard to remove!

#### Assembly Videos

We now have a full set of videos showing the assembly process linked on the github main page, and at ossm.tech You can also find links to online CAD models to help see how things go together!

### Mate the Base Plate with the Motor

Attach the OSSM base plate to the motor with (2) 5x20mm cap head screws in the locations marked _M5_ and tighten with a M5 nut below the motor mounting flange. The nut is usually kept from turning by the motor body. If it spins when tightening, insert a flat head screwdriver between the nut and motor to keep it in place.

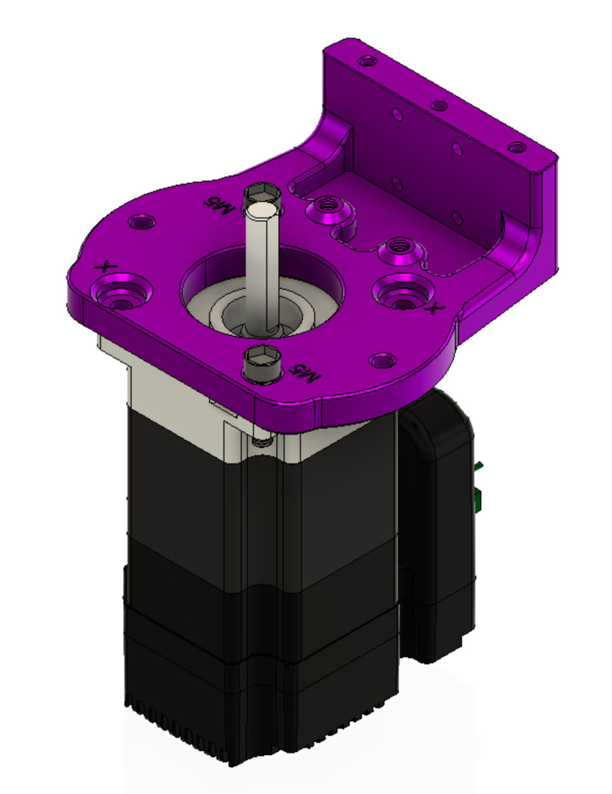
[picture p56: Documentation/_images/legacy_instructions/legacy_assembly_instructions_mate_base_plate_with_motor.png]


### Build up the belt idler bearings

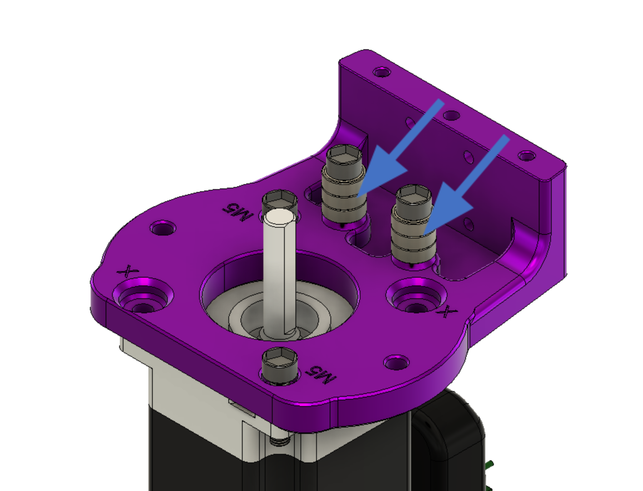
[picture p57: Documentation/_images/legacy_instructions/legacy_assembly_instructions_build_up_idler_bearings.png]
build\_up\_idler\_bearings
\

The idler bearing stacks are built up around 5x20mm cap head screw\
\
Stack three 5x11x4mm bearings on a 5x20mm cap head screw and attach to the threaded positions in the baseplate as shown above.

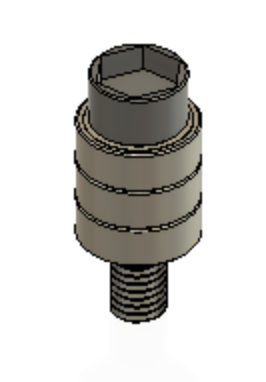
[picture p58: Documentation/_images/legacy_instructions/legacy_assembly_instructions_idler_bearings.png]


### Install and Align the Pulley

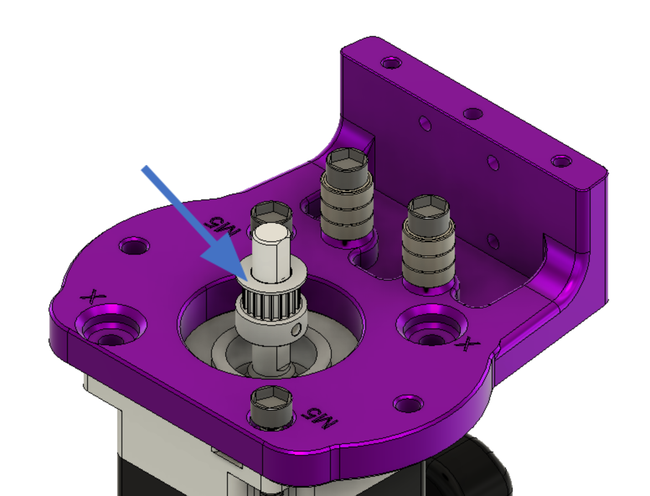
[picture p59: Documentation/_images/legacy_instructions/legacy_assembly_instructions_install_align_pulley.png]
install\_align\_pulley


* Mount the 20 tooth GT2 Pulley on the shaft of the motor
* Make sure you line up one of the set screws with the flat on the motor!

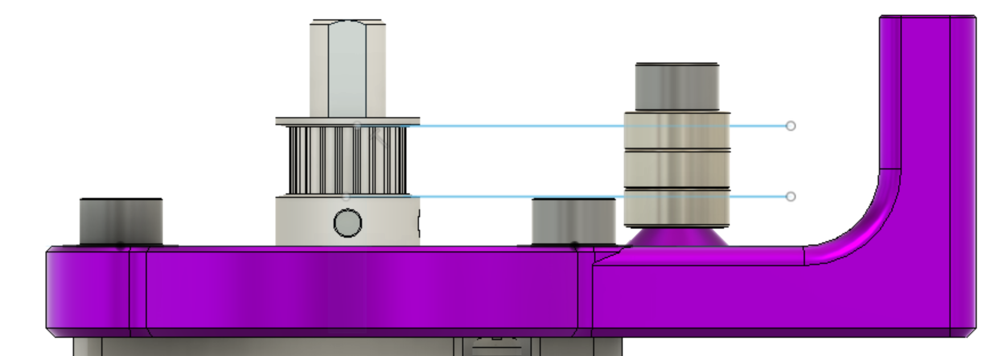
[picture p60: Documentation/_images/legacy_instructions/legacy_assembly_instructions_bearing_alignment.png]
\

### Linear Rail Installation

Align the pulley so that it is within the range of the bearings and the set screws that clamp it to the motor shaft are available from above the base plate

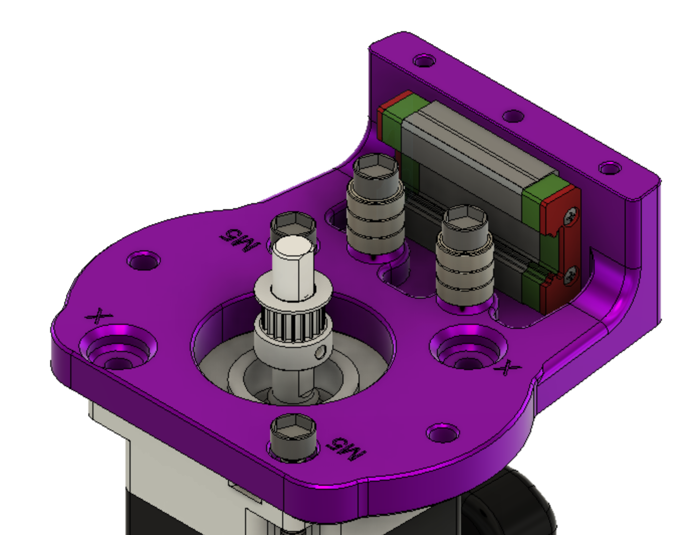
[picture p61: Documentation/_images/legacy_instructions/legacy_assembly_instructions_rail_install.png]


MGNRH Rail and Bearing are next. _linear rail is omitted from this view._

\
\

**Be careful not to separate bearing from linear rail, there is a chance of losing ball bearings when the rail and bearing are separated!**\
\

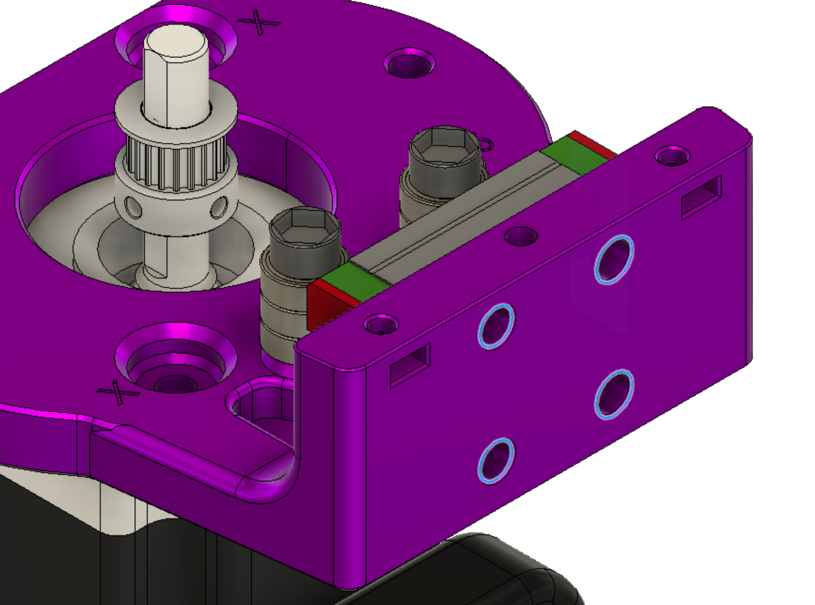
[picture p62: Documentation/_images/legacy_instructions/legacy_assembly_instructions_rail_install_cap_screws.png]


Highlighted holes for M3 cap screws. The cap screws should finish flush with surface when fully tightened.

\
\
\

Attach the middle part of the OSSM body utilizing the remaining diagonal holes. The M5x20mm shown below being inserted into the correct positions.

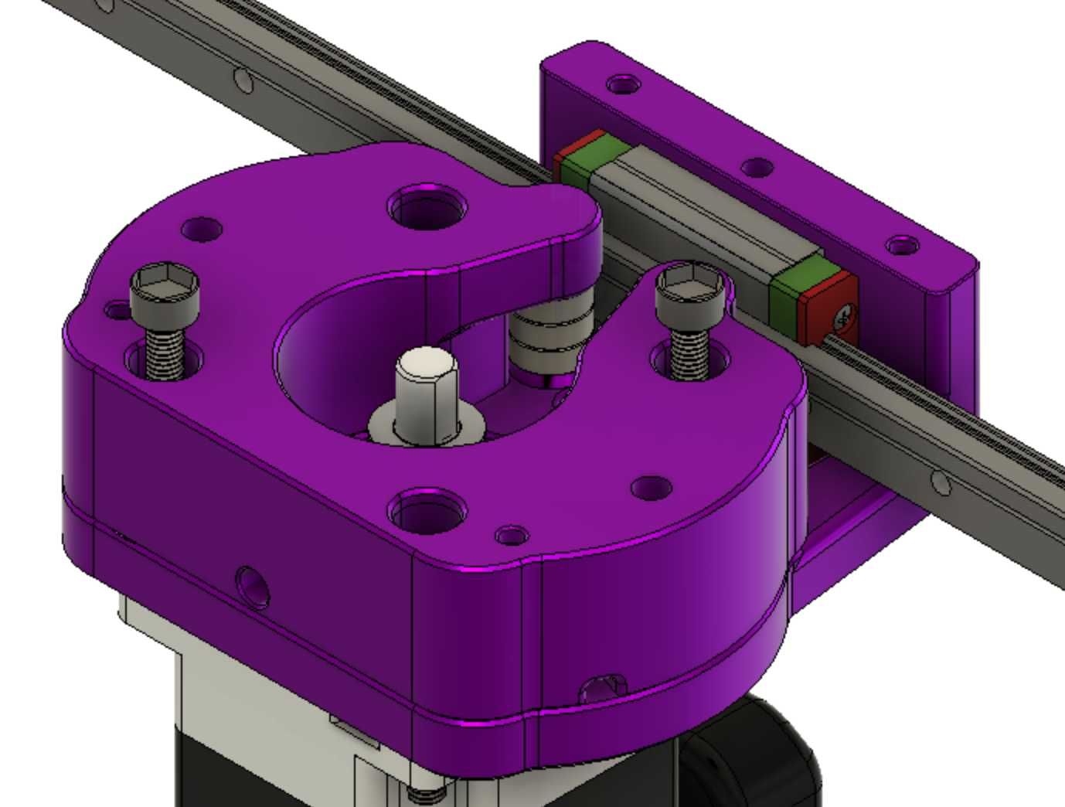
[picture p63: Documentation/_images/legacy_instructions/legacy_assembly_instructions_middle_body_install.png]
\

### Alternate Middle – Pivot

The new middle pivot design makes it easier to bolt your ossm directly onto extrusion. It can be mounted using 4x M5x35 screws and 4x M5 nuts as shown below.

Here all 4 bolts go through the motor, ossm base, and ossm middle.

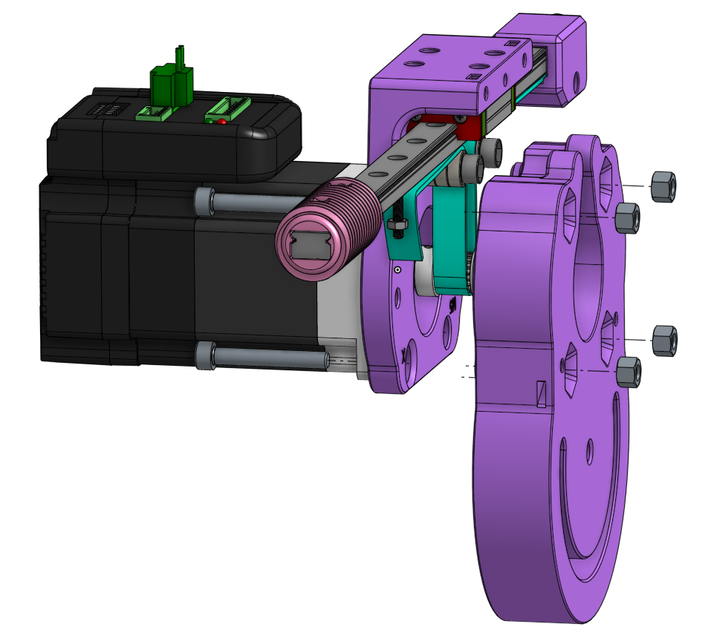
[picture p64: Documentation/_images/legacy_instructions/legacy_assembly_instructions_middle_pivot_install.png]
\

### Belt Placement

Now is time to place the belt in the iconic OSSM configuration. Using the clamp files provided to secure and tension the belt.\
Belt is shown in BLUE\
The teeth on the belt are not shown, but should face the pulley.

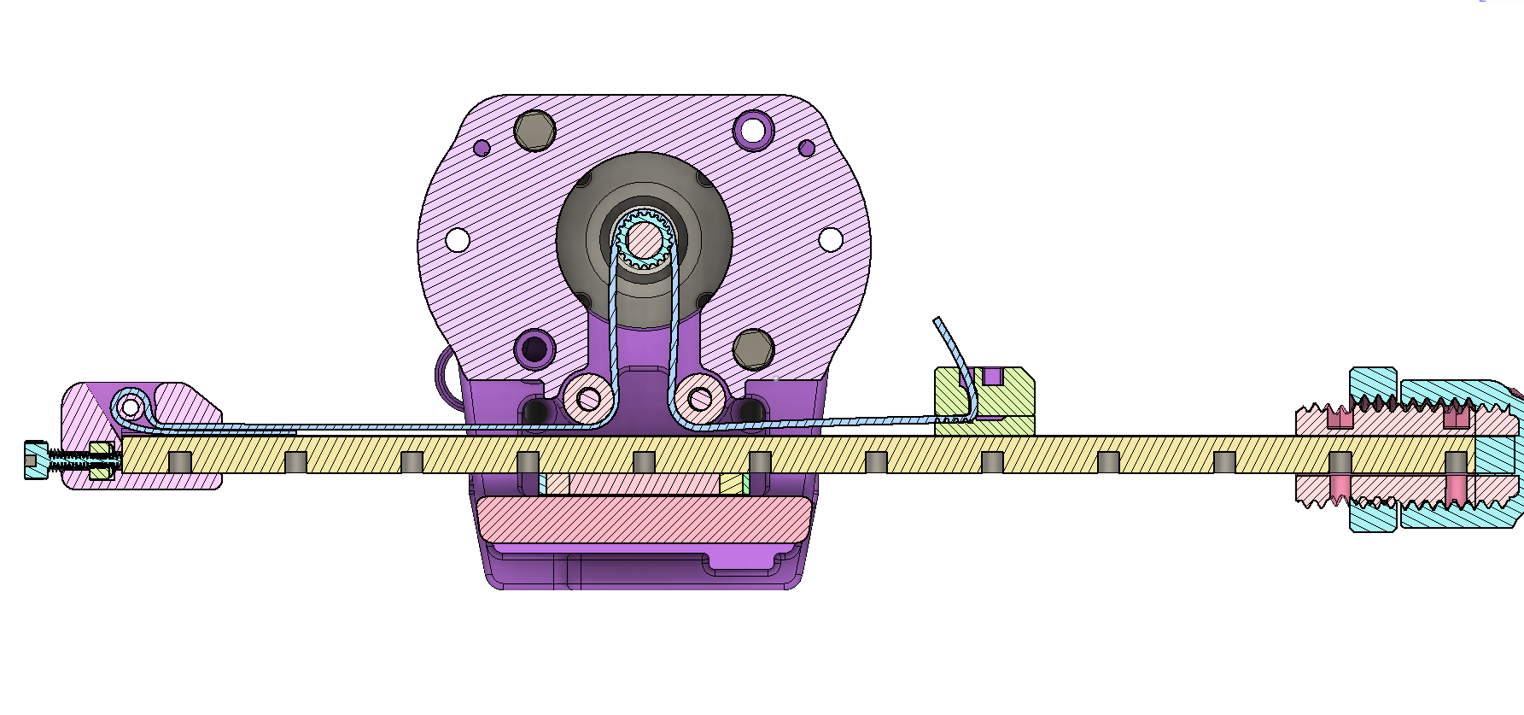
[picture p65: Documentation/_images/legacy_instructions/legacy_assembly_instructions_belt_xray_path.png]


X-Ray View of entire belt path

\

### Belt Tensioner

Start with getting the belt placed into the tensioner. Fold the belt in half with the teeth facing towards each other. Work each end in from the top following the green arrows below.\
Pull the belt until the lower piece has only a small section sticking out from the tensioner.

Then slip the assembly onto the end of the rail.

Drop an M5 nut into the slot and thread in an M5x16 screw into it. Tightening this screw will push on the rail and apply more tension – be gentle here! We just want to take up the slack, it is easy to apply way too much force if you tighten this too much. Too much force can damage your motor bearings!

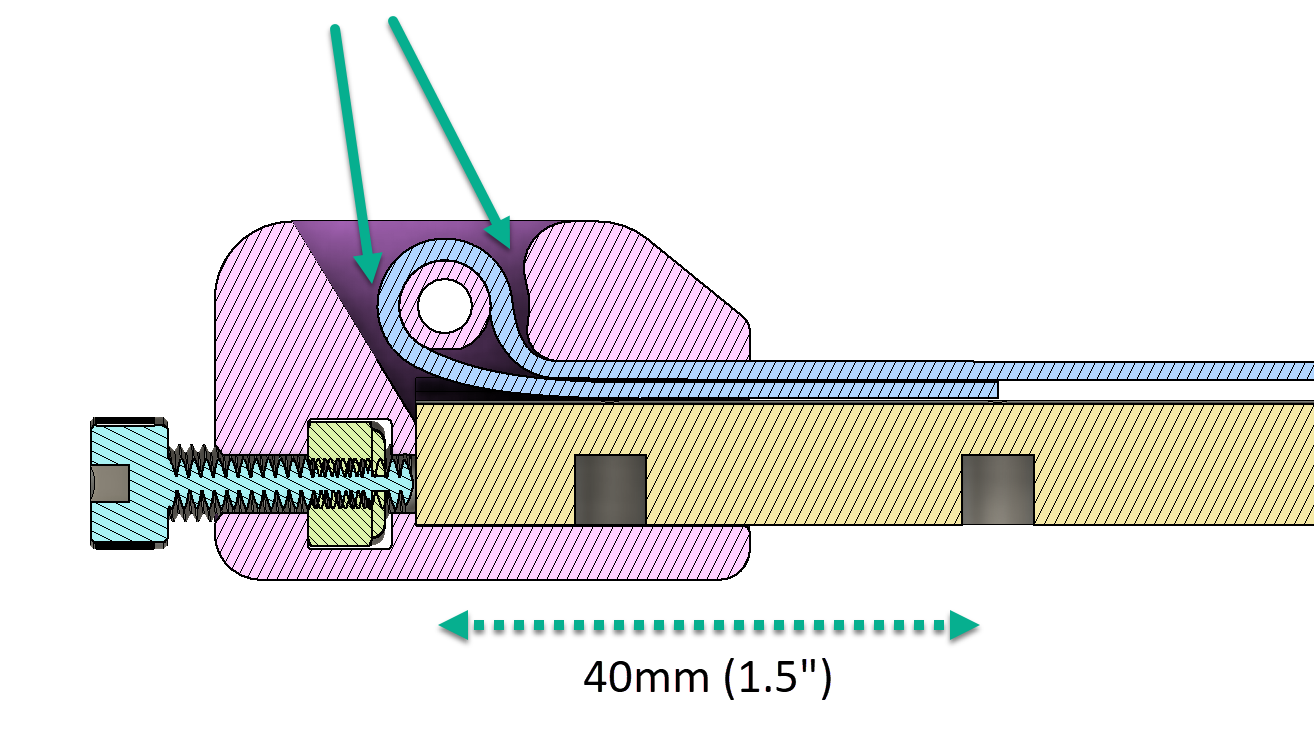
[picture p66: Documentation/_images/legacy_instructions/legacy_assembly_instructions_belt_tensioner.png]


### Wrap Belt Around Pulley

Wrapping the belt around the main drive pully and past the stacks of idler pulleys will get the belt in the correct location.

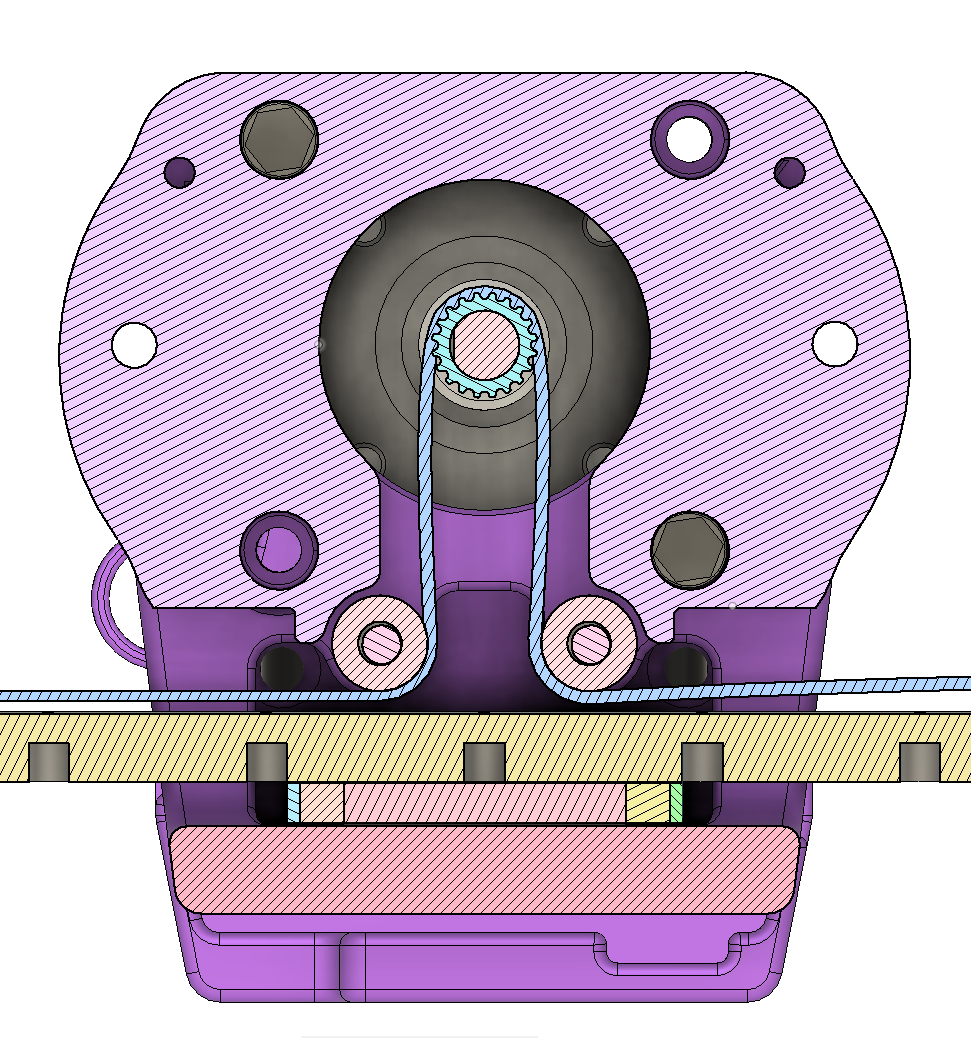
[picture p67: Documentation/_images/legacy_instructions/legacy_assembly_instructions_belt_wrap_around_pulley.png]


### Belt Clamp

* The belt routes through the slot in the top belt clamp. Insert the M3x20 screw from the bottom of the rail, through the clamp bottom (with teeth up engaging the belt), and engage the nut in the top clamp.
* Before you tighten the screw fully, pull the remaining belt slack so it is snug.
* Tighten the screw to secure the belt.
* Trim remaining belt (if you are sure you are happy with stroke length!)

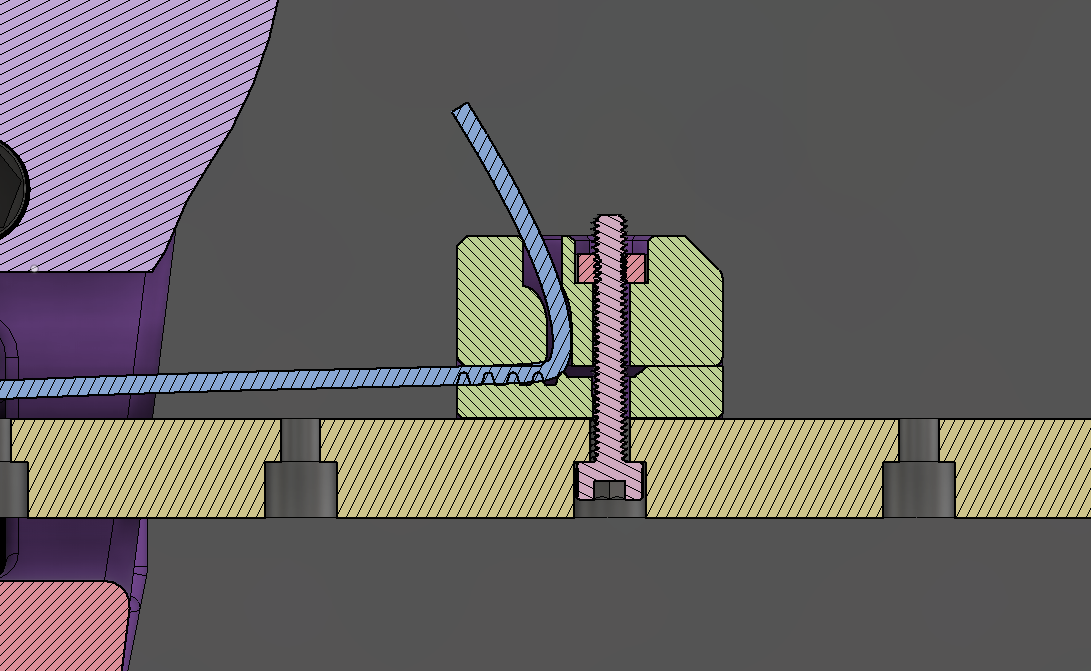
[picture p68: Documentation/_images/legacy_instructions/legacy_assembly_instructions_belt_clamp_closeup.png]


Congratulations!

(we hope) You should now have a mechanically assembled OSSM Reach out on the discord if you have any issues!

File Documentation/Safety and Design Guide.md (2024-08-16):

# Safety and designing for the OSSM

One of the great things about the OSSM is it can be modified by anyone.  This means if you are going to use, modify or contribute to the OSSM project you need to be aware of the risks and potential hazards.  After all, an OSSM is poking around in some very intimate and soft places.  There are moving belts and motors that have a surprising amount of force all of which can hurt people.  

Our analysis identifies three areas of hazard; design, build and use which neatly map to groups of people.  You may be a member of all three groups or only one, but most people are builders and users.  

***Designers*** who contribute to the OSSM project or create their own modifications.  As a designer you have a role to ensure what you design is safe.  This may be a part, code or a pattern.  You should also provide guidance to builders and if required users on both hazards and ways to manage them. We recommened you download and review the hazard analysis spreadsheet for more details.  

***Builders*** are the people that take an OSSM from an idea into a physical reality from components, printed parts and then assemble it into a working machine.  As a builder you need to ensure that what you build is strong enough to for use and keep the user safe with the designed controls.

***Users*** fall into two subgroups and you can be both at once.  Operators and the receptive user who is having all the fun.  Good design and a quality build can provide some protection. But keep in mind, a misused OSSM can create hazards that cannot be mitigated by design.  

## Guidance for designers

- Think about any new hazards that your design may introduce.  Some ideas cannot be made safe, but other risks can be managed with careful thought.
- Inclusive design is often safer design.   Designing for people that are visually, physically or cognitively impaired is hard but there are many benefits.
- FDM/3D printed materials have some qualities you need to be aware of.  Layer orientation, material choice all can have a positive (or negative) impact on safety.
- For safety critical cases be aware of the limitations of software.  Programming for safety is harder than it looks and there is a considerable body of knowledge devoted to it.  If you can find an alternate hazard mitigation such as a power switch that will be more reliable than a software interrupt.  
- Don’t expect users and builders to “do the right thing”.  A designer is often best placed to understand the potential issues.  A builder may not identify risks and users are often distracted when using an OSSM.

## Guidance for builders

- Get to know your 3D printer and filament.  For critical parts print with thicker walls, larger layer heights and hotter temperatures than normal to maximize strength.  Resin printers do not typically create strong enough prints to be used safely.
- Think about finishing and sharp edges.  An OSSM is frequently used with minimal clothing and users are often distracted.
- Try to avoid relying on the user of the OSSM to "do the right thing” and work around build deficiencies or missing parts such as covers.  

## Guidance for users

- Understand the risks of using an OSSM.
- Use appropriate toys.  
- Take frequent breaks.
- Perform an inspection prior to use.  Don’t operate an OSSM with missing or broken parts.
- Don’t operate an OSSM while suffering temporary cognitive impairment.
- Think about over penetration risks.  Being restrained and unable to move away from the machine greatly increases risk and chance of injury.
- Lube, lube, lube

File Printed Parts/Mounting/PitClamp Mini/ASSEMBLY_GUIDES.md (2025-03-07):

##   PitClamp Mini - Body Assembly  
[PitClamp Mini - Body Assembly  
https://www.youtube.com/watch?v=61Ln6gqgMoM](https://www.youtube.com/watch?v=61Ln6gqgMoM)  

##   PitClamp Mini - Ring 57AIM Installation 
[PitClamp Mini - Ring 57AIM Installation  
https://www.youtube.com/watch?v=yFO8ejC_tYA](https://www.youtube.com/watch?v=yFO8ejC_tYA)

##   PitClamp Mini - Ring iHSV57 print post processing
[PitClamp Mini - Ring iHSV57 print post processing  
https://www.youtube.com/watch?v=xeE-M1KEnYc](https://www.youtube.com/watch?v=xeE-M1KEnYc)

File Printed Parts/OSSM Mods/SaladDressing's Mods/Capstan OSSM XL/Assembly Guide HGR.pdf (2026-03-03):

1. Bushing Pulley/Spindle/Drum/Capstan:
1. With the Bushing Pulley files printed, make sure the Bushing/Bearing Shell fits on top of the drum. Shouldn't be too loose or too tight. Top Part needs to fit on top as well with a somewhat secure fit. Also assure the pulley fits onto the motor shaft. Shouldn’t be too tight or loose. If things don't fit, adjust with the included .f3d file or pm me.
2. Take the bushing and slide the 24 mm shrink tubing on top. Cut it off so it fits well.
3. Heat the shrink tubing with a lighter or a heat gun. You can hold the bushing with some tongs or pliers, so you don’t burn yourself. Make sure to heat everywhere so it sticks to the bushing properly.
4. Spread some epoxy 2 part glue on the Bottom printed file.
5. Slide the Bushing/Bearing Shell on top. Put on the top part as well.
6. Put some weight on the Pulley and let it dry for 24h under pressure
7. Make sure the bushing holds well. It should be very rigid.

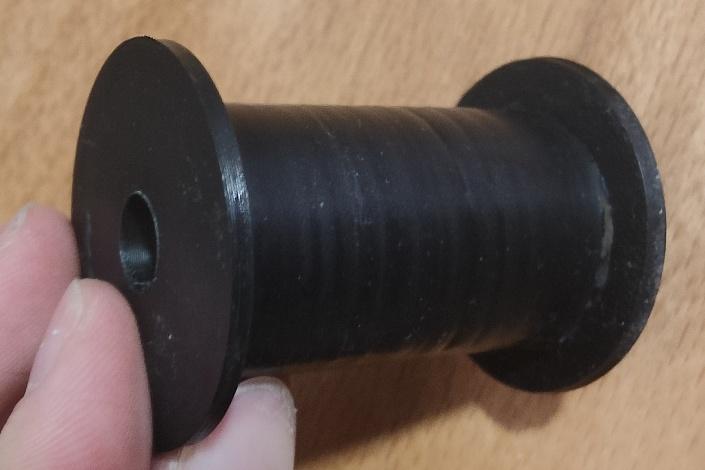
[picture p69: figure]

2. Clean the HGR20 Rail and HGH20HA Carriage (e.g. soaking in 99% isopropyl alcohol). Lube the carriage up well before mounting with some silicone grease

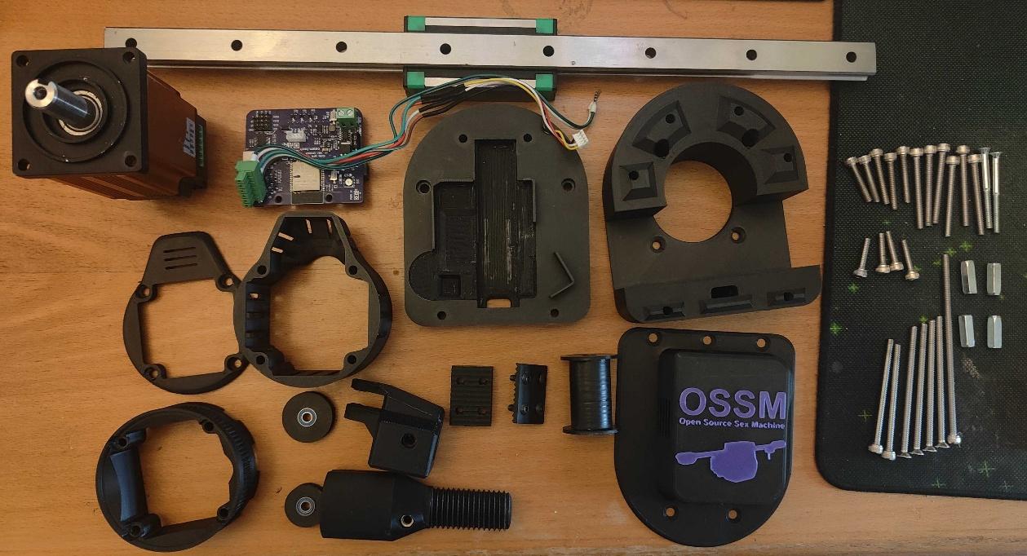
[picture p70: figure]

3. Mount the Motor Head Back to the Motor with Armpit’s 60AIM40F Ring behind (optional, if you want PitClamp Mounting) with 2 Hex Cap M5x65, 2 Countersunk M5x45 Screws and 4 M5 Nuts on the back. If you want to use the Motor Cover (https://github.com/SaladDressingHW/Salads-OSSM-Additions/tree/main/60AIM40F%20Motor%20Cover) replace the Nuts with M5x20 Coupling Nuts (as pictured). Make sure the Motor Terminal and the Notch in the Motor Ring are aligned to each other and the cable hole in the Motor Head Back right below the motor shaft. Ignore the cable in the second picture.

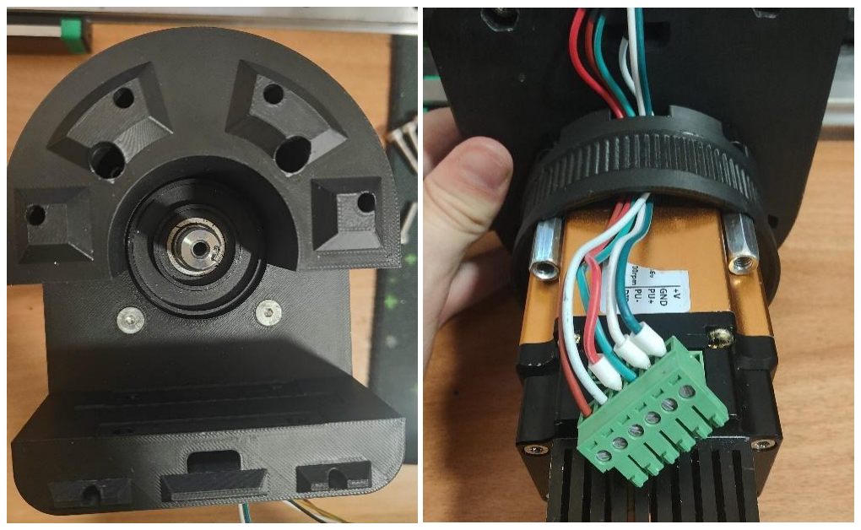
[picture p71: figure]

1. Screw the HGH20HA Rail Carriage to the Motor Head Back with 4 Hex Cap M5x20 screws. Slide the rail onto the carriage with the help of the plastic guide.

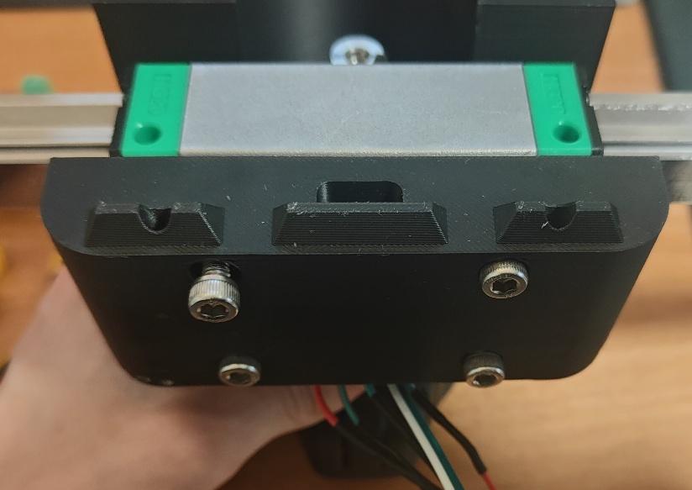
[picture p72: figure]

2. Slide the Rail End and End Effector onto the ends of the rail in the exact orientation shown below.

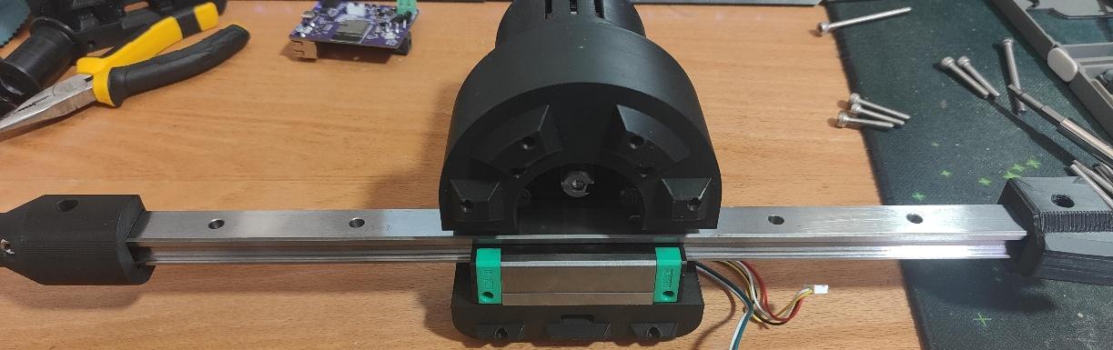
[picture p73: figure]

3. Fasten End Effector and Rail End each with a M5x30 Hex Cap Screw and a M5 Nut on the other side.
4. Insert 2 MR115 bearings each into big and small end pulleys. Mount the bigger pulley onto the Rail end with a M5x25 Hex Cap and the smaller one onto the End Effector with a M5x30 Hex Cap, as shown below. Use one M5 Nut each.


5. Slide the Capstan Drum onto the motor head.
6. Slide the motor head on the rail so it is roughly centered on the usable rail.
7. Take the rope and guide it through the circular hole on the side of the motor head through the “main channel” and out in the front (see pictures). Tie one end to a hole on the rail of your choosing. This makes the wrapping of the rope easier. Leave a generous length of rope on this end. Do not cut the rope.
8. Guide the rope around the End Effector’s Pulley from bottom to top.


9. Wrap the rope rather tightly around the capstan pulley. The amount of wraps I used was 8, which works well with the Shrink Tubing I use. Your mileage may vary depending on how you increase the friction of the bushing. This is something you may need to play around with. More wraps have only the disadvantage of taking up more space, which makes it not possible to accommodate higher rail lengths. 8
wraps works well with 450mm rail length. Not
enough wraps will result in slipping of the rope.


The more wraps, the harder it is for the rope to slip. When you are done, roughly center the wraps on the drum by sliding them around.
10. Guide the rope as pictured below and slide the end through the circular hole on the left side of the motor head, again through the “main channel” and out through the front (see pictures).


11. You can let go of the rope. This will relieve some tension from the wraps, but that is no problem, we can tension it as much as we like later.
12. Push the pulley onto the motor shaft completely. Screw it onto the shaft using a M5x25 Hex Cap screw. You don’t need to screw it very tight.


13. Take the Motor Head Front part. Push in the standoffs in the fitting slots. Use violence if needed. Make sure it fits properly and take out the bottom one as that obstructs the next steps.
14. Push 4 M4 and 1 M5 Nuts into the lower part of the tensioner.
15. Insert the lower part of the tensioner into the Motor Head front part as pictured below.
16. Push the Tensioner around a bit to make sure it moves around.
17. Put the Motor Head Front onto the Motor Head Back with 2 M5x65 Hex Cap Screws and slide the rope through the appropriate passthrough hole.

18. Flip the rope ends up, onto the Tensioner and tension them by pulling them. Now put the top part of the Tensioner on top and screw it tight with 4x M4x12 ISO7380 screws. Ignore the cables in the picture.


19. Take the 300mm JST Header cable as well as some awg 18 or thicker (not too thick) 2 pin cable (power cable). Don’t cut anything off
20. Crimp one end of the power cable.
21. Route the power and JST cable through the main channel and Motor ring to the Motor. Screw the crimped end of the power cable and the cable end of the JST cable into the motor terminal. Check the labels on motor and control board pcb. They need to match.


22. Check Cable lengths. Look at a picture further down how the PCB is mounted. There needs to be enough cable to mount it without tension. Avoid having too high lengths of cable though. Cut it shorter if needed.
23. Crimp the other ends of the cable.
24. Connect JST Header and Power cable to the control board.
25. Screw an M5x110 Hex Cap screw from the top of the Motor Head Front through the Tensioner. Turning this screw will slide the Tensioner up and therefore tighten the rope. Tighten it a bit for now.
26. Clip on the lowest standoff back onto the Motor Head Front.


27. Now turn the M5x110 screw to tension the rope. Tension it guitar string tight. Move around the rail a bit and see if anything is wrong. The motion should be very fluent. Make sure the rope wraps are roughly centered on the capstan pulley. If they are not, it may be that it gets hard to push the rail to the end because the rope wraps over itself (thus increasing diameter of the capstan pulley -> longer rope needed). If you have issues with this and can’t get it to work, feel free to pm on discord.
28. The rope will stretch a tiny bit over the first few hours of use. Retension accordingly to keep it guitar string tight or even tighter. The tighter the rope is tensioned, the less shifting on the rope on the drum you will have (in extreme conditions). I haven’t played around with limits on how tight is too tight, but at some point the tensioner will probably fail. Before use, always make sure the rope is properly tensioned.
29. Cut the rope now but leave some redundancy in length.
30. Finally, screw down the front cover with 4x M5x75 countersunk screws and 4x M5 Nuts on the back.


31. Have fun!

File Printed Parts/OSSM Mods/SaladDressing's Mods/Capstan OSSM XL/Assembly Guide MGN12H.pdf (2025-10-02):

1. Bushing Pulley/Spindle/Drum/Capstan:
1. With the Bushing Pulley files printed, make sure the Bushing/Bearing Shell fits on top of the drum. Shouldn't be too loose or too tight. Top Part needs to fit on top as well with a somewhat secure fit. Also assure the pulley fits onto the motor shaft. Shouldn’t be too tight or loose. If things don't fit, adjust with the included .f3d file or pm me.
2. Spread some epoxy 2 part glue on the printed file.
3. Slide the Bushing/Bearing Shell on top. Put on the top part as well.
4. Put some weight on the Pulley and let it dry for 24h under pressure
5. Make sure the bushing holds well. It should be very rigid.
6. Wrap some grippy tape around the pulley. I used kinesio tape, which works quite well


2. Clean the MGN12H Rail and Wagon (e.g. soaking in 99% isopropyl alcohol)
3. Screw the MGN12H Rail wagon to the Motor Head Back with 4 HexCap M3x12 screws
4. Mount the Motor Head Back to the Motor with Armpit’s 60AIM40F Ring behind (optional, if you want PitClamp Mounting) with 2 Hex Cap M5x45, 2 Countersunk M5x45 Screws and 4 M5 Nuts on the back. Make sure the Motor Terminal and the Notch in the Motor Ring are aligned to each other and the cable hole in the Motor Head Back right below the motor shaft.


5. Insert 2 MR115 bearings into the 8mm end pulley, 3 MR115 bearings into the 12mm end pulley.
6. Secure the 8mm Pulley to the end effector and the 12mm end pulley to the rail end with a ISO 7380 M5x20 screw each.
7. Slide End Effector and Rail End onto the rail as pictured below. Secure the End Effector with 2x M3x16 Hex Cap Screws and the Rail End with 1x M3x12 Hex Cap Screw


8. Channel the jst and 2 pin cable through the central hole below the motor shaft on the Motor Head Back
9. Slide the Pulley onto the motor head. Do not slide it on completely, just push it on enough for it to have a somewhat stable fit. This will make the wrapping of the rope easier.
10. Slide the motor head on the rail so it is roughly centered to the usable rail.
11. Take the rope and tie one end to a hole on the rail of your choosing. This makes the wrapping of the rope easier. Leave a generous length of rope on this end. Do not cut the rope.
12. Guide the rope around the end pulleys and the capstan like pictured below.


13. Wrap the rope rather tightly around the capstan pulley. Try to keep the wraps on the drum roughly centered. The amount of wraps I used was 8, which works well with the Kinesio tape I used. Your mileage may vary depending on which tape you used. This is something you may need to play around with. More wraps have only the disadvantage of taking up more space, which makes it not possible to accommodate higher rail lengths. 8 wraps works well with 450mm rail length. Not enough wraps will result in slipping of the rope. The more wraps, the harder it is for the rope to slip.

14. If you use the 3d printed Pulley with the integrated grooves (not the bushing pulley), same applies here, though you will need less wraps. 5 was enough if I remember correctly.
15. Guide the rope as pictured below


16. You can let go of the rope. This will relieve some tension from the wraps, but that is no problem, we can tension it as much as we like later.
17. Push the pulley onto the motor shaft completely. Screw it onto the shaft using a ISO 7380 M5x12 screw. You don’t need to screw it very tight.
18. Take the Motor Head Front part. Push in the standoffs in the fitting slots. Use violence if needed.
19. Push 4 M4 and 1 M5 Nuts into the lower part of the tensioner.
20. Insert the lower part of the tensioner into the Motor Head front part as pictured below. Insert the M5x80 screw from the appropriate hole on top and screw it into the lower tensioner part.


21. Push the Tensioner around a bit to make sure it moves around.
22. Put the Motor Head Front onto the Motor Head Back. For this, first guide the jst and 2 pin cables through the hole just below the tensioner. Then untie the rope end and guide both rope ends through the same hole.


23. Insert 4 ISO 7380 M4x12 screws into the tensioner top part.
24. Tension the rope ends and pull them over the teeth of the tensioner.
25. Place the tensioner top part onto the lower part and screw it tight. You can make it quite tight.


26. Make sure the rope goes over the little blocks on the underside of the Motor Head Front, as pictured below


27. Mount the Top with 2 M5x45 Hex Cap screws and 2 M5 Nuts on the back
28. Now turn the M5x80 screw to tension the rope. Tension it guitar string tight. Move around the rail a bit and see if anything is wrong. The motion should be very fluent. Make sure the rope wraps are roughly centered on the capstan pulley. If they are not, it may be that it gets hard to push the rail to the end because the rope wraps over itself (thus increasing diameter of the capstan pulley -> longer rope needed). If you have issues with this and can’t get it to work, feel free to write on discord.

29. Hold the rope ends tightly, screw of the tensioner top part, and reset the position of the tensioner back down again. Then screw in the tensioner top part again. This is done so you have some redundancy in retensioning.
30. The rope will stretch a tiny bit over the first few hours of use. Retension accordingly to keep it guitar string tight or even tighter. The tighter the rope is tensioned, the less shifting on the rope on the drum you will have (in extreme conditions). However, too tight of a tension may damage the tape on the capstan pulley over time. Before use, always make sure the rope is properly tensioned.
31. Cut the rope now but leave some redundancy in length.
32. Crimp the cable ends with terminal crimps.
33. Plug the JST cable into the header on the ossm control board and screw in the cable ends into the terminal block
34. Place the ossm control board onto the standoffs with the side with the esp chip facing down.
35. Cut the cables to length and screw the other side into the motors terminal.
36. Finally, screw down the front cover with 4x M5x45 countersunk screws and 4x M5 Nuts on the back.


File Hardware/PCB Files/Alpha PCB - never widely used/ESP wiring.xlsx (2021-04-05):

 |  | ESP32 Lolin32
 | Connection | Pin Label | Pin Label
 | 3.3V rail | 3V | GND
 |  | EN | TX
 |  | VP | RX
 |  | VN | 3V
 | Analog distance signal | 32 | 22 | SCL out to QWIIC | QWIIC pin 4 | I2C
 | Touch input | 33 | 21 | SDA out to QWIIC | QWIIC pin 3
 | battery voltage sense | 34 | GND |  | GND
 | Tactile button input | 35 | GND |  | VCC
 | charging /5v digital sense | 25 | 19 | MISO to screen2 |  | SPI
 |  | 26 | 23 | MOSI to screen2
 | Touch input | 27 | 18 | SCK to screen2
 |  | 14 | 5 | SS to screen2
 |  | 12 | 3V
 |  | 13 | 17 | NEO Pixel output
 |  | 5V | 16
 |  | GND | 4
 |  |  | 0
 |  |  | GND
 |  |  | 2
 |  |  | 15
The pins marked SCL and SDA (on other SPI displays sometimes labeled as SCLK and MOSI, respectively)

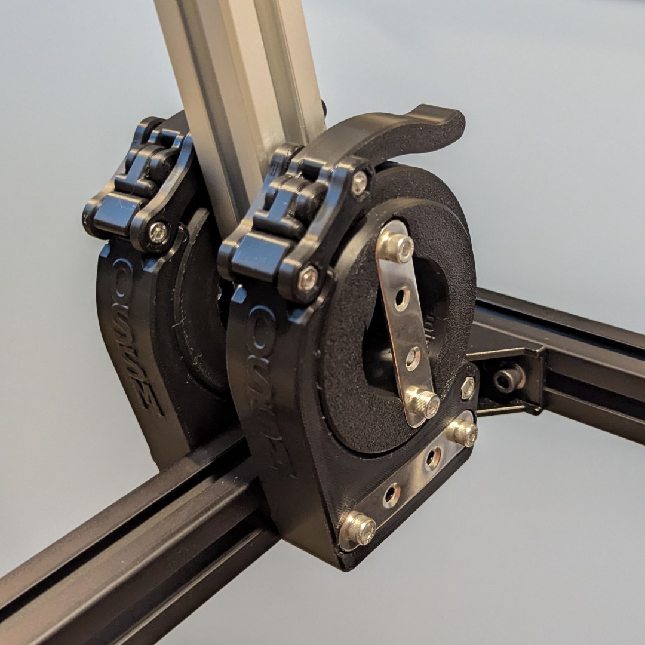
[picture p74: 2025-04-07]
Printed Parts/OSSM Mods/PitClamp Mini Reinforced 3030 Hinges/Images/Assembled Stainless.jpg

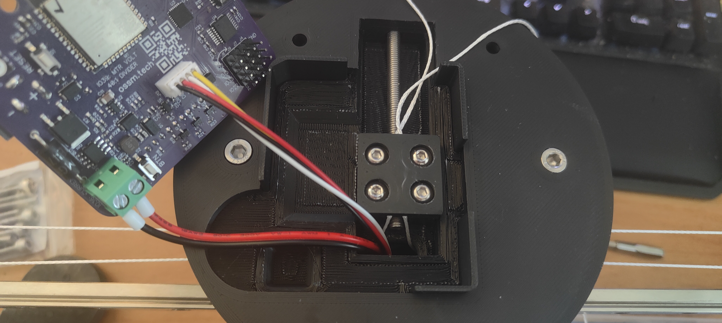
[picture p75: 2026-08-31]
Printed Parts/OSSM Mods/SaladDressing's Mods/Capstan OSSM XL/Pictures/Assembly/17.jpg

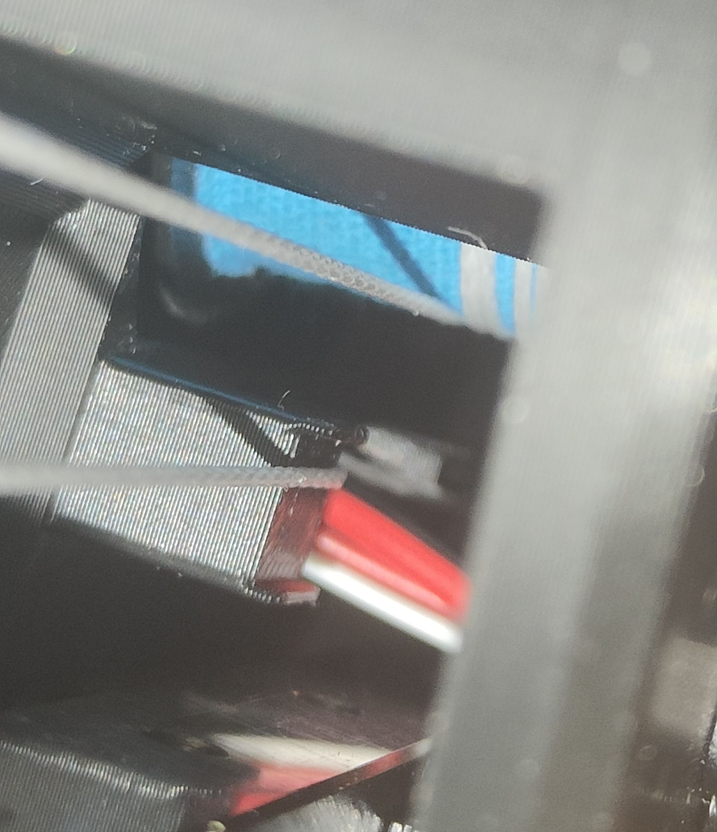
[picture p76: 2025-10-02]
Printed Parts/OSSM Mods/SaladDressing's Mods/Capstan OSSM XL/Pictures/Assembly/16.jpg

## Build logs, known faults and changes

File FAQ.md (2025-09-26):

# Frequently Asked Questions

### Q: What is OSSM?

A: An OSSM is compact sex machine that can be customised to suit you. Based around a NEMA23 pattern for electric motors it can be driven by stepper or best of all servo motors it uses a combination of 3D printed and off the shelf parts.

### Q: Why go to all this trouble? Why don't you just buy a ready made machine?

A: The OSSM is open you are not tied to a specific company and it does a lot more than equivalently priced machines. Best of all you can fully control the stroke speed and most importantly depth. You can make patterns or even your own control software. Maybe you want to add a stroker rather than a dildo, you can modifiy it to do that. Not enough power? You can use a bigger motor up to a certain point.

### Q: What parts do I need?

A: Head over to [the README](./#bill-of-materials) - the BOM is maintained there.

### Q: I've been reading about motors and now I'm really confused

A: While you can theoretically use any Nema23 mount motor. There are motors that work and some that work better. Stepper motors are cheaper and noiser so the community recommends closed loop servo motors. These are more efficient and more importantly easier to program.

### Q: What strength of motor do I need?

A: That depends on a couple of factors.

- Vaginal or Anal use
- Size of toys
- Anticipated Speed

We don't have a lot of recorded data [Please help us with this!] however the general suggestions are;

- **NEW 57AIM30 (Gold Motor)**: Roughly equivalent to **180W** below, see [Gold Motor Info](https://github.com/KinkyMakers/OSSM-hardware/blob/master/Documentation/Gold-Motor.md) and BOM.
- **100w** IHSV57 Servo: Vaginal usage with medium size toys and Anal usage with smaller toys (10 lbs force)
- **140W** IHSV57 Servo: Vaginal usage with larger toys, Anal use with medium size toys (15 lbs force)
- **180w** IHSV57 servo works with a wide range of toys for vaginal or anal play, and really packs a punch (20 lbs force). However if you like seriously heavy fantasy dildos you might want to consider building a Squooter [see the discord] that uses and even a larger motor mount; the NEMA34 which has even more powerful motors.

A build with a servo motor will have a flat torque curve across the speed range. That's to say - it will push just as hard at the slow speeds as well as the fast.
With a stepper, the most force will be at the slower speeds and the top speed of a stepper is much less than the servo we've chosen to work with.

### Q: Hold on, why does anal play need more powerful motors?

A: Butts have big powerful muscles! It's common for people to bear down, or clench when things are feeling really good. Also it can be pretty fun shoving big objects in there! It can take a big motor to handle a big toy in a poweful butt.

### Q: What sized 3D printer do I need?

A: The minimum bed size is 105mm x 105mm for the largest single piece. Approximately 125mm of height is required for the shorter vac-u-lock compatible adapter, the plate is significantly shorter.

### Q: What print material is best?

A: Structural parts should be printed in a strong material such as simple PLA, PETG, ABS, ASA, or PCTG. Non-structural parts may be printed in whatever material you like. Note that additives such as those used to make matte materials may weaken the material, so be sure to check the material properties before using a filament with additives. If you print in some new and unusual material, please share that in the Discord!

### Q: What is the infill percentage?

A: 30% has been found to work just fine with PLA for non flexible parts

### Q: How thick are the walls and top?

A: Recommend at least 3mm for non flexible parts.

### Q: What are these flexible parts and how should I print them?

A: There are mounting solutions that use clamps for the OSSM these need some flexiblity. For these parts thinner walls 2mm, lower infill percentages and a gyroid pattern.

### Q: How do I mount toys onto the OSSM?

A: Aside from the motor this is second decision. There is a vacc-u-lock compatible mount the double double and a plate mount for suction cup toys that has some points to tie a dildo down The OSSM Platten

### Q: What to I mount the machine on?

A: Well there are a few designs available. THere are standard pipe mounts for US/Canadian along with 80/20 rails that can be used like a construction set. There are even manfrotto boom compatible adaptors. It is really limited by you imagination.

### Q: How do I control my OSSM

A: It depends on how you are going to use it. Basic OSSM control is via the wired remote and a more advanced remote is available from community members (M5 Remote). If you want something specific you can create your own that is the great thing about open source hardware.

### Q: I heard somewhere you can "control via a web page?" Can I get people to control my OSSM over the internet?

A: As of August 2023 you cannot control an OSSM over the internet. In the past R&D offered a web page that allowed very basic control with speed and depth settings over wifi.

### Q: X-Toy and funscript support. Where is it?

A: As of August 2023 there is a highly experimental X-toy firmware forked from an earlier version that requires endstops. This code has significant issue and is not considered to be safe for use on humans. There are frequent pauses, it loses track of where it is and has a tendency to randomly extend to maximum depth. Development of an X-Toys firmware is happening but it is complicated.

### Q: Why is X-Toys/Funscripts/ButtplugIO so difficult?

A: Things are a lot more complicated once you dig down into them.

- The motion core does not yet support position streaming. This is in development and requires a complete redesign of the safety architecture as you don't want to accidentally stab yourself.
- From the experimental software we learnt that the latency margin is really thin, Bluetooth especially struggles here. This will be a challenge to overcome.
- The data models of both xtoys and Buttplug.io do not support complex data models as it would be required for OSSM out of the box. As scaling to the full length of OSSM is just not an option. There might be a workaround by emulating an other toy. But you won't be able to control all aspects of OSSM through this.

### Q: There is an OSSM reference board do I have to buy it to make an OSSM?

A: No you don't but it does make building an OSSM a lot easier and stops you having to solder anything.

### Q: Powersupplies what size do I need?

A: That is linked to the size of motor. The higher the wattage of motor the larger the powersupply you need. For safety use a desktop power supply that is ideally double insulated. Power supplies from Mouser/Digikey/Conrad/RS etc are all typically more expensive than "no brand supplies" you get from AliExpress/eBay/Amazon. Experience has been mixed with unbranded supplies with occasional quality and longer term stability issues.

- 100w JMC we currently suggest a 4A 24V Supply
- 140w /180w JMC we currently suggest a 6A 24V

### Q: How long should the H-rail be?

A: It is really up to you but a 350mm rail will give approximately 195mm of depth.

### Q: What is the size of the 24mm Thread for the End Effector?

A: It is a M24x3 (this is the size on the machine, do a test print for your new End Effector, you may have to upsize by 3-5%)

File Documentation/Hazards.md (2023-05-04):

| Hazard | Vulnerability | likely consequence | Design mitigation | Build mitigation | User mitigation | Notes |
|---|---|---|---|---|---|---|
| Body parts caught in OSSM mechanism | Exposed pullies and bearings | Trauma to tissue | Cover for pully and bearings | Apply cover | | |
| Body parts caught in OSSM mechanism | Pinch point front and rear of linear rail | Trauma to tissue | Cover for pully and bearings | Apply cover | User avoids placing hand in area | |
| Hair caught in OSSM mechanism | Users hair gets dragged into OSSM drive mechanism | Trauma to tissue, loss of hair, worst case partial scalping | Cover for pully and bearings | Apply cover | Operator does not lean over OSSM in use. <br/><br/>Tie back hair.  <br/><br/>Use of OSSM only below waist.  <br/><br/>Full enclosure in skin tight latex (just to see if anyone else reads this) | |
| Failure of dildo screw mount | FDM prints can fail along deposition lines resulting in sharp splinters or exposed rail | Trauma to tissue, internal injuries, cuts and bleeding. | Screw thread protects the metal rail.  The rail supports the thread reducing stress on FDM part.  <br/><br/>Recommended settings for wall thickness and infill. | Builder must use appropriate materials with sufficient adhesion (temperature), layer height optimized for strength.  Thicker walls and appropriate infill | User ensures any toys are correctly mounted to reduce stress. | |
| Failure of interchangeable dildo head  | FDM prints can fail along deposition lines resulting in sharp splinters | Trauma to tissue, internal injuries, cuts and bleeding. | Designers ensure there is sufficient strength in designs around likely failure points such as screw thread, mounting platters and external walls. <br/><br/>Design to avoid possibility of shards pointing in direction of OSSM movement towards the user.  <br/><br/>Recommended settings for wall thickness and infill. | Builder must use appropriate materials with sufficient adhesion (temperature) layer height optimized for strength.  Thicker walls and appropriate infill | User ensures any toys are correctly mounted to reduce stress. | |
| OSSM penetrates too deeply | Due to a software fault the OSSM penetrates too deeply injuring the user | Trauma to tissue, internal injuries. | Code review and testing. <br/><br/>Software architecture that isolates depth and positional controls into specific section of code that is tightly managed.  <br/><br/>Design for an emergency stop that cuts power to the motor <br/>Provision of hardware rear stop to reduce effective rail length.<br/><br/>Dildo adaptors with wide platter/bases to act as a physical stop.  <br/><br/>Recommendation of "safer rail lengths" to engineer a control.  <br/><br/>Introduction of position for use cases requiring a longer rail.  | Use as shorter rail as possible to minimize risks <br/><br/>Do not over specify motor to reduce available torque.<br/>  <br/>Implement emergency stop control for stepper motor.  <br/><br/> | User of machine should be able to move away from hazard.  Avoid restraints <br/><br/>Shorter toys with less depth<br/><br/>Toys with wider bases that cannot "over penetrate" | GPIO and software controls do not effectively mitigate risks as in the case of software failure they will not interrupt in sufficient time. |
| OSSM penetrates too deeply | As the result of operator error the OSSM penetrates too deeply injuring the user | Trauma to tissue, internal injuries. | Dildo adaptors with wide platter/bases to act as a physical stop.<br/><br/>Identify clear requirements for stands including weight and dynamic load. <br/><br/>Consider failure modes of material and manufacturing techniques such as FDM and model orientation.  <br/><br/>Specify recommended materials, wall thicknesses and infill percentages.  <br/><br/>Ensure stands have multiple points securing each adjustment point.<br/><br/>Ensure stands are stable in all dimensions. | Use as shorter rail as possible to minimize risks <br/><br/>Do not over specify motor to reduce available torque.<br/>  <br/>Implement emergency stop control for stepper motor.  <br/><br/> | Operator awareness and communication.<br/><br/>Do not make physical adjustments when OSSM is operating.  <br/><br/>User of machine should be able to move away from hazard.  Avoid restraints <br/><br/>Shorter toys with less depth<br/><br/>Toys with wider bases that cannot "over penetrate" | |
| OSSM penetrates too deeply | Due to the failure of a stand the OSSM penetrates too deeply injuring the user | Trauma to tissue, internal injuries. | Dildo adaptors with wide platter/bases to act as a physical stop.<br/><br/>Identify clear requirements for stands including weight and dynamic load. <br/><br/>Consider failure modes of material and manufacturing techniques such as FDM and model orientation.  <br/><br/>Specify recommended materials, wall thicknesses and infill percentages.  <br/><br/>Ensure stands have multiple points securing each adjustment point.<br/><br/>Ensure stands are stable in all dimensions. | Make stands from appropriate materials using designer guidance.<br/><br/>Ensure hardware and fasteners are of sufficient strength. | User of machine should be able to move away from hazard.  Avoid restraints <br/><br/>Shorter toys with less depth<br/><br/>Toys with wider bases that cannot "over penetrate"<br/><br/>Use your specific OSSM within the design parameters and if repurposing a design perform a hazard assessment. | |
| Electrocution | Over amperage results in electrical fire | Burns, electruction | Specify power supplies with correct amperage <br/><br/>Design PCB cover to protect higher voltage components<br/><br/>Use 50V or less power supplies. | Purchase power supplies with correct amperage <br/><br/>Include appropriate cover in build | Do not handle with wet hands.<br/><br/>Do not touch body of OSSM when in operation adjust via the stand. | |
| Electrocution | OSSM circuit board is splashed with body fluids | Burns, electruction | Design cover to protect PCB from body fluids.  This implies PCB cover should protect the side of the board facing the user.  <br/><br/>Stand designers design OSSM orientation and position to avoid contact with fluids and reduce the risk of pooling. | Implement appropriate cover for design and stand combination. | Use your specific OSSM within the design parameters and if repurposing a design perform a hazard assessment. | |
| Malicous use | A remote malicous user takes over internet remote control of users OSSM when in manual operation injuring the user via over penetration | Trauma to tissue, internal injuries. | Remote control lock out when local control is being used by default. <br/><br/>Software to allow configuration that is per powercycle.  Remote must be enabled after each restart.<br/> | | | Dual control ability is often used in remote estim with inexperienced drivers.  Maybe an override? |
| Electro Magnetic Interference (EMI) | EMI from a poor quality power supply causes unpredicatble movement of the OSSM effector via the wired remote| Trauma to tissue, internal injuries. | | |Use good quality power supplies from a reputable manufacturer. |This hazard was reported by a community member when they used a budget unbranded power supply. Issue resolved with substitution of good quality PSU |

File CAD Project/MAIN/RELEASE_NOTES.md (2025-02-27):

# OSSM CAD Project Release Notes

## 02.27.2025

### OSSM - Stand
- **3030 Extrusion - Handle Spacer**
  - Added 1mm tolerance for washer

### OSSM - Actuator
- **Body - Middle**
  - Removed internal thread that should not be present
- **Body - Middle Pivot**
  - Removed internal thread that should not be present
- **Body - Bottom**
  - Added 0.5mm chamfer leading into bearing threads to aid alignment and improve layer strength where threads engage

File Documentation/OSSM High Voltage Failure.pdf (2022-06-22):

# OSSM Board – High Voltage Failure

This issue affects Rev 2 orders with order number #1214 or lower. Anything after that has this fix applied to it.

### Problem:

If you plug in the board using a 30V or higher supply without a motor connected, there is a very short voltage spike (1 us – about a millionth of a second) that kills the DC-DC converter.
Note - This does not occur if you are using standard 24V or if you have a motor connected to the board.

### Solution:

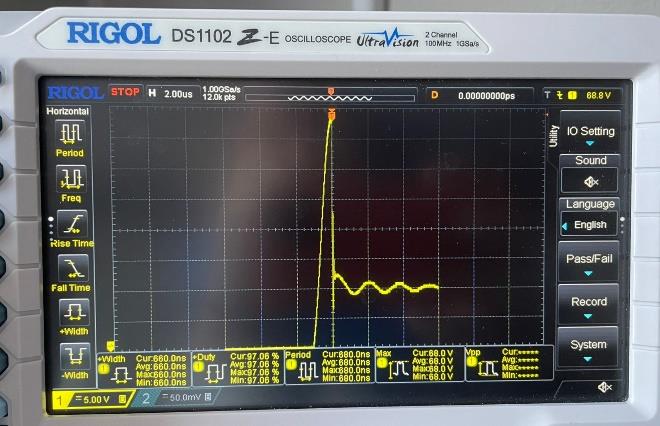
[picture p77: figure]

Add a TVS (transient voltage suppression) diode. This clamps the input spike to a voltage that the DC-DC converter can tolerate.

Part number:

1.5KE51CA (https://www.digikey.ca/en/products/detail/littelfuse-inc/1-5KE51CA/688036) – This part is about $1, and widely available.

You can add the diode by bending the leads and soldering to the board as shown below. We recommend trimming the pin marked to make sure it isn’t too close to the diode lead.

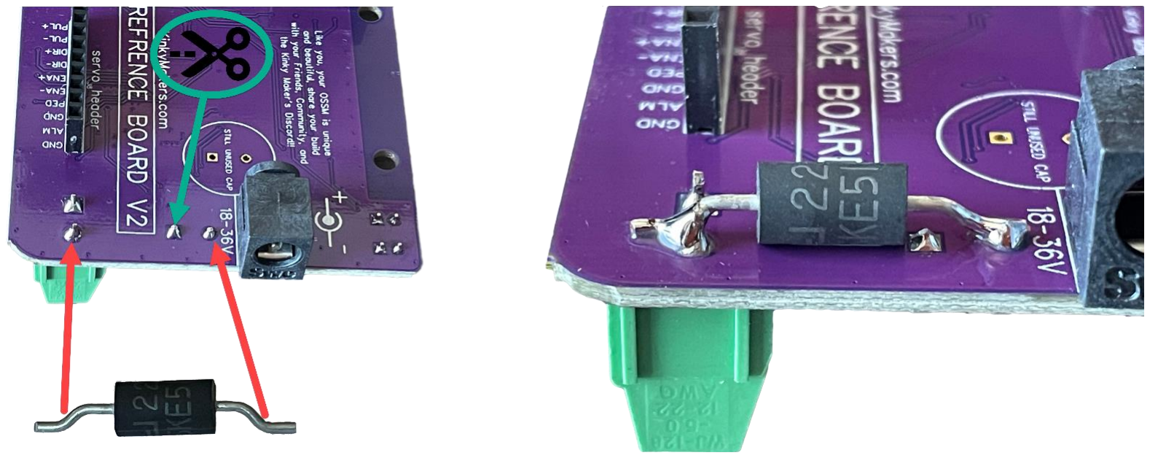
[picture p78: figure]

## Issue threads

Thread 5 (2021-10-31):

add all eagle files for hardware

ferengi82, 2021-10-31:
hi, if possible please add the *.sch file for the reference-board and the *.sch and *.brd for the remote

greatpirategalaxy, 2023-05-04:
Gerber files exist in the repository,

Closed 2023-05-04.

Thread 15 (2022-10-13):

Large mounting plate threads are misformed

Arkanoid0, 2022-10-13:
the large mounting plate option (Hardware/OSSM Printed Parts/end effector options/24mm threaded/Vampix 24mm Tie Down and Suction Plate - LARGE.stl) has misinformed threads as designed, the threads end before exiting the boss preventing the screw from threading.

ortlof, 2022-10-13:
Hi Thanks. Fixed it Uploads will be done in the next days.

greatpirategalaxy, 2022-10-14:
Version 2 files added to the repository.

Closed 2022-10-14.

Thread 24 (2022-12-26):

add PDF schematic

flaretek, 2022-12-26:
Please upload a PDF of the schematic for the OSSM board.

greatpirategalaxy, 2023-05-04:
Schematics exist in v2 and V1 folders

Closed 2023-05-04.

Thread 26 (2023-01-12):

Electronics Board V2.1 won't store WiFi credentials

moarkaboom, 2023-01-12:
After accessing the wifi setup page, I connect to my wifi and enter the credentials. The OSSM reboots and I can see it come online very briefly on my router, but as soon as it's done booting, it disappears from my network.
When I reboot and connect to the wifi setup page again, it says "No AP set" even though I configured it.
I cant seem to get it to store the credentials and stay connected to my network.

greatpirategalaxy, 2023-05-04:
Addressed on Discord

Closed 2023-05-04.

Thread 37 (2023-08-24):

BOM missing screws

SugoiShades, 2023-08-24:
watching the assembly video, it clearly shows 6 M5x20 but the BOM lists that you only need 4, could someone double check the other screw counts and see if they are accurate?

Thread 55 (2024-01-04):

PlatformIO guide points to outdated files

fickleforms, 2024-01-04:
https://github.com/KinkyMakers/OSSM-hardware/blob/master/OSSM%20PlatformIO%20Readme.md

This points to e.g. the "PlatformIO ESP32 code" directory, which no longer exists, and references OSSM_Main.ino, which also no longer exists.

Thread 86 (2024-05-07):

#82 No distance tracking in stroke engine

MarvFPV, 2024-05-07:
#82
While in Stroke engine, the distance tracking currently does not work.

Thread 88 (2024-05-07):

#82 No homing after resetting from inside stroke engine

MarvFPV, 2024-05-07:
#82
Resetting the OSSM with a longpress from inside Stroke engine does not initiate rehoming after reset. This then necessitates the user to either powercycle the OSSM or to press the reset switch.

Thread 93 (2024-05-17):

After installing firmware rail length detection fails - no power to motor

greatpirategalaxy, 2024-05-17:
After installing firmware fails POST on rail detection.  Motor is no powered at all.  Installed M5 firmware works fine.

iHSV 140W, 503 FW
Version 2.1(?) board

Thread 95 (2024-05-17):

Add progress bar during homing

laueno2, 2024-05-17:
Currently, users won't know if the screen is stuck or not during homing. It would be helpful to include a progress bar, like the startup logo screen example below, showing expected rail length (100mm) and actual rail length measured (0) so far. This should improve the user experience by keeping them informed and preventing them from feeling stuck during homing. It also aids in troubleshooting homing issues, such as mismatches between measured and actual lengths.

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

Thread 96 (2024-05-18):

Pulse per rev must be set at 800 to not time out

greatpirategalaxy, 2024-05-18:
iHSV 140W rev 503
Ref board 2.1

Pulse per rev must be set at 800 to not time out during rail length detection.

stanikeva, 2024-09-21:
Hey @greatpirategalaxy is this issue still open? If so, is there more information available for this?

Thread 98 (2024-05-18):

Right hand button works intermittently during operation

greatpirategalaxy, 2024-05-18:
Action of right hand encoder button fails to reliably register long, short or double click.  Seems to return to main menu.

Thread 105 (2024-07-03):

The Rail is not mentioned in the BOM of the assembly guide

Johnr24, 2024-07-03:
The Rail is not mentioned in the BOM of the assembly guide

It's missing there's no link to what spec to get,

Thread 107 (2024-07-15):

Gold Motor documentation missing

Ortho-Max, 2024-07-15:
Docs list Gold Motor as "proposed". in `Gold-Motor.md`.
There is no mention of it at all on the BOM, FAQ etc.
There is no mention of 42AIM30 in docs whatsoever.

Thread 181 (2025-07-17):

Potential depth/stroke setting safety issue with standard wired remote

vendeta44, 2025-07-17:
Idk if I experienced a bug last night or just user error. But I had a issue were my depth was seemingly instantly changed from about 25% to 100% when I went to change stroke patterns.

from my build thread

"I'm not clear if this was user error or a software bug. When it happened I had just switched to change stroke engine profiles and visibly could see that menu on my screen. Once I could see the menu was when the depth started advancing. What I'm a little iffy about is whether I started twirling the knob before the menu appeared and set the depth by accident or if the menu got stock and twirling the knob to change stroke pattern instead changed the depth. It usually takes quite a few turns to get all the way to min/max depth so I don't think I managed to jump the gun by that much, but its possible i guess."

**On further investigation I think I found the root cause.  Its possible to spin the knob during the double press to change menus, and that spin will be preserved even as the remote changes visible menus resulting in a depth (or stoke/sensation) adjustment that is both unintended and not clearly communicated as the screen switches away from showing the previous setting.**

**Also related, but different stroke engines treat the depth/stroke different. I suspect the reason why I seen such rapid adjustment of the depth is two fold, I initiated a spin when I double pressed AND I continued to spin once the menu changed and selected a stroke setting that operated differently causing the OSSM to bypass the slow depth advancement safety. Basically I was operating in a "push" mode where it pushed to the depth with the first stroke engine, and switched it to a "pull" mode, essentially allowing a near instantaneous adjustment of depth(advances at the speed setting)**

Potential fix could be some sort of failsafe that if the menu change double press is initiated the machine automatically falls back to the depth/stroke/sens settings from 2 seconds prior, that way even if unintentional adjustment is made its automatically cancelled out.

I'm on mainline firmware with standard remote, should be fully updated, haven't reflashed it via computer recently but I have done wireless updates.

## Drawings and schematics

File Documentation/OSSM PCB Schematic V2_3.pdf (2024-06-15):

DC Power and Spike Suppressor | Input Buck and LDO, max. 40V | ESP-WROOM-32D

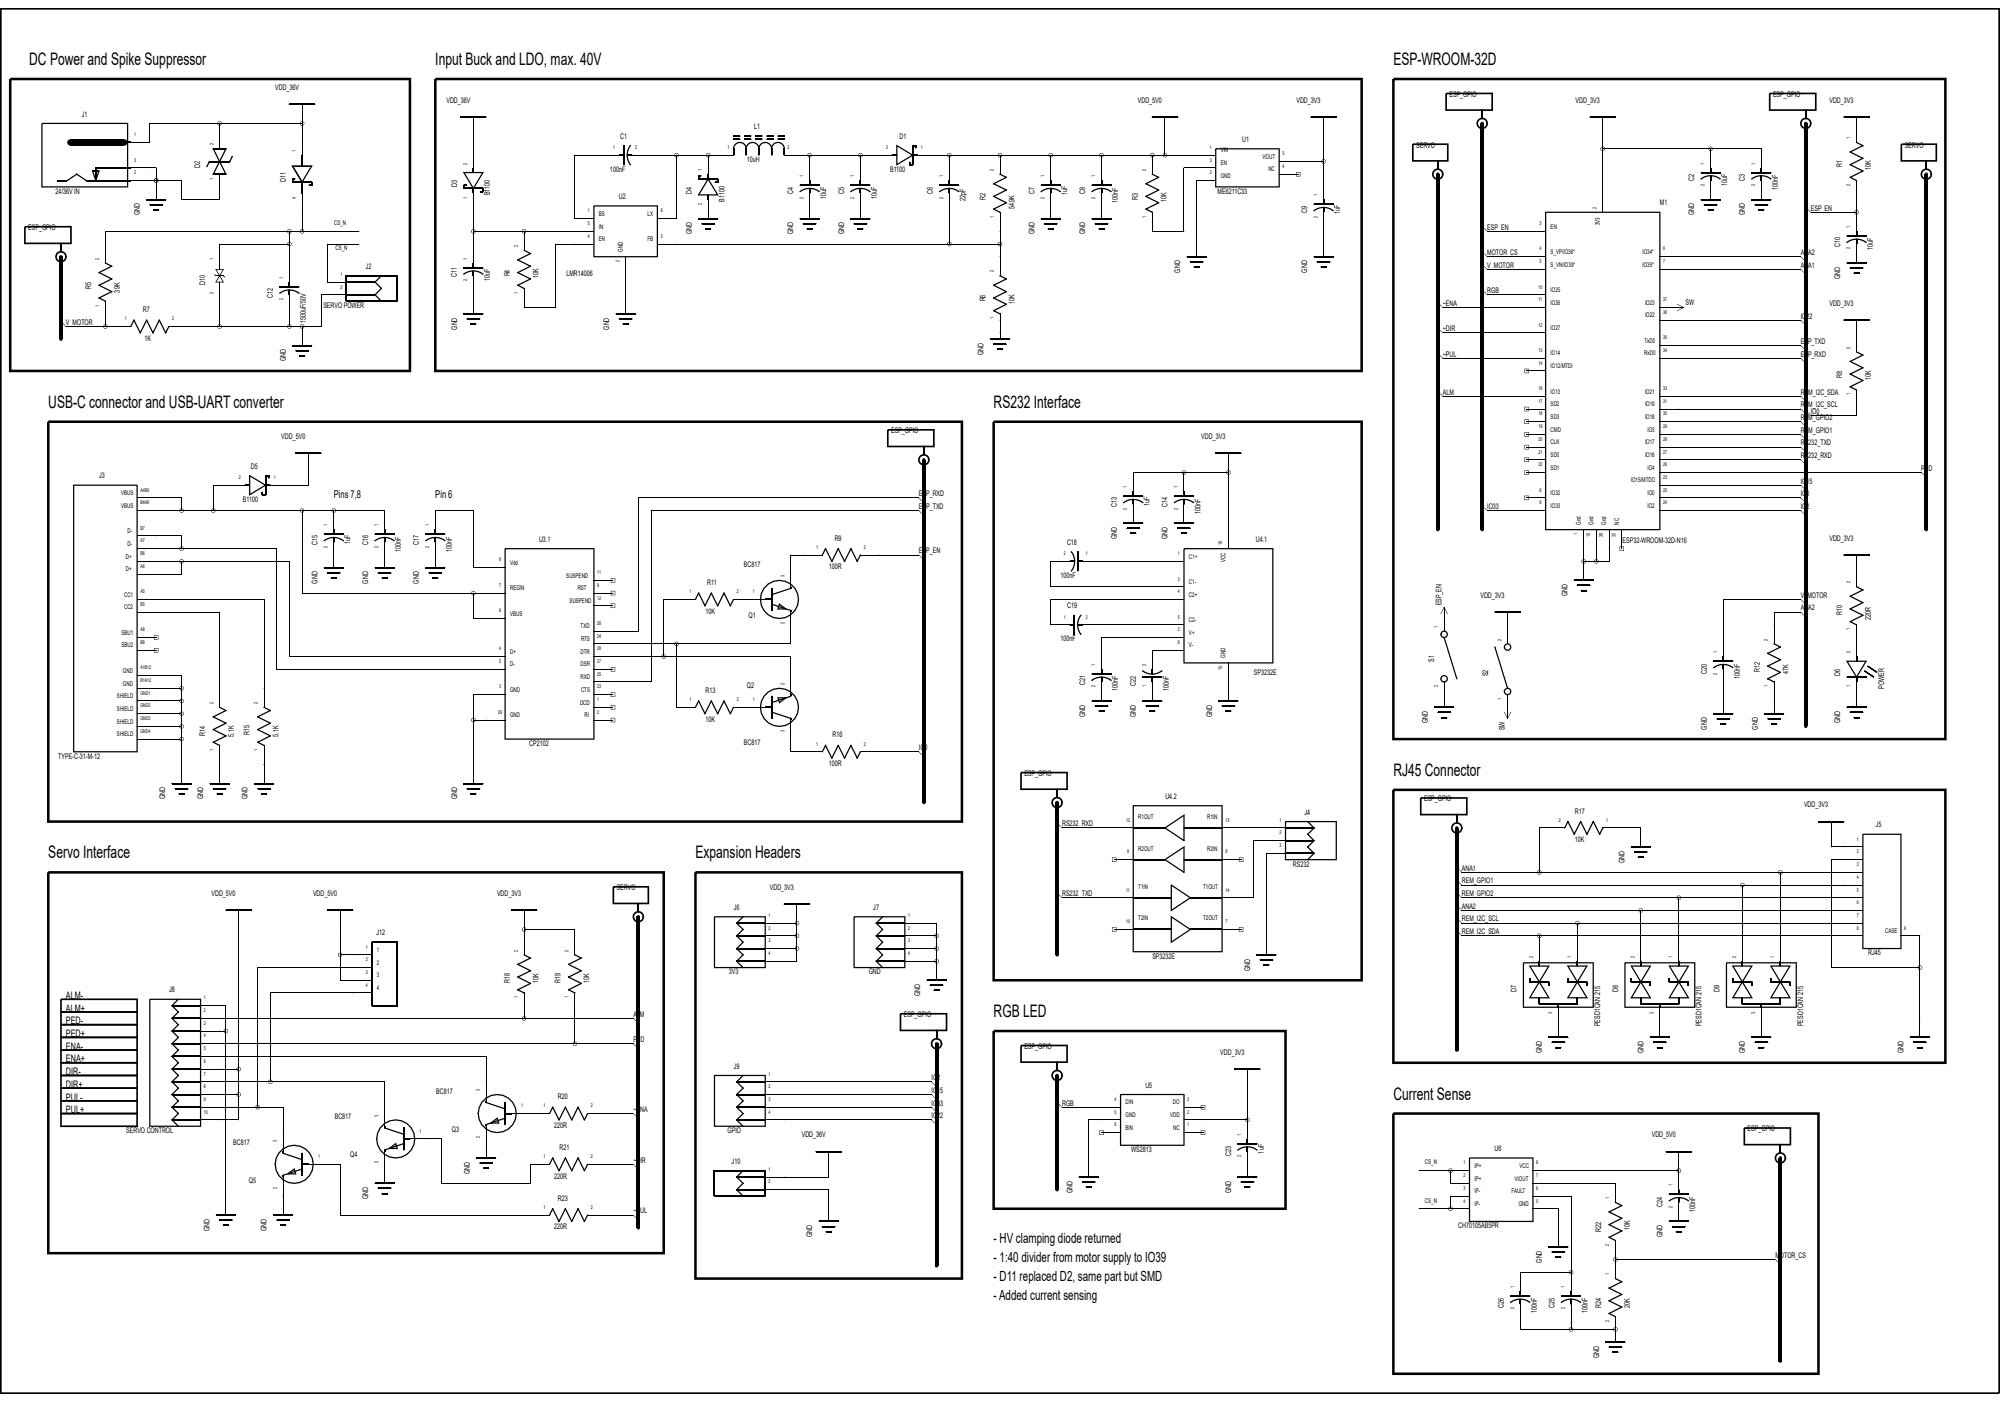
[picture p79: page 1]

USB-C connector and USB-UART converter

- HV clamping diode returned
- 1:40 divider from motor supply to IO39
- D11 replaced D2, same part but SMD
- Added current sensing

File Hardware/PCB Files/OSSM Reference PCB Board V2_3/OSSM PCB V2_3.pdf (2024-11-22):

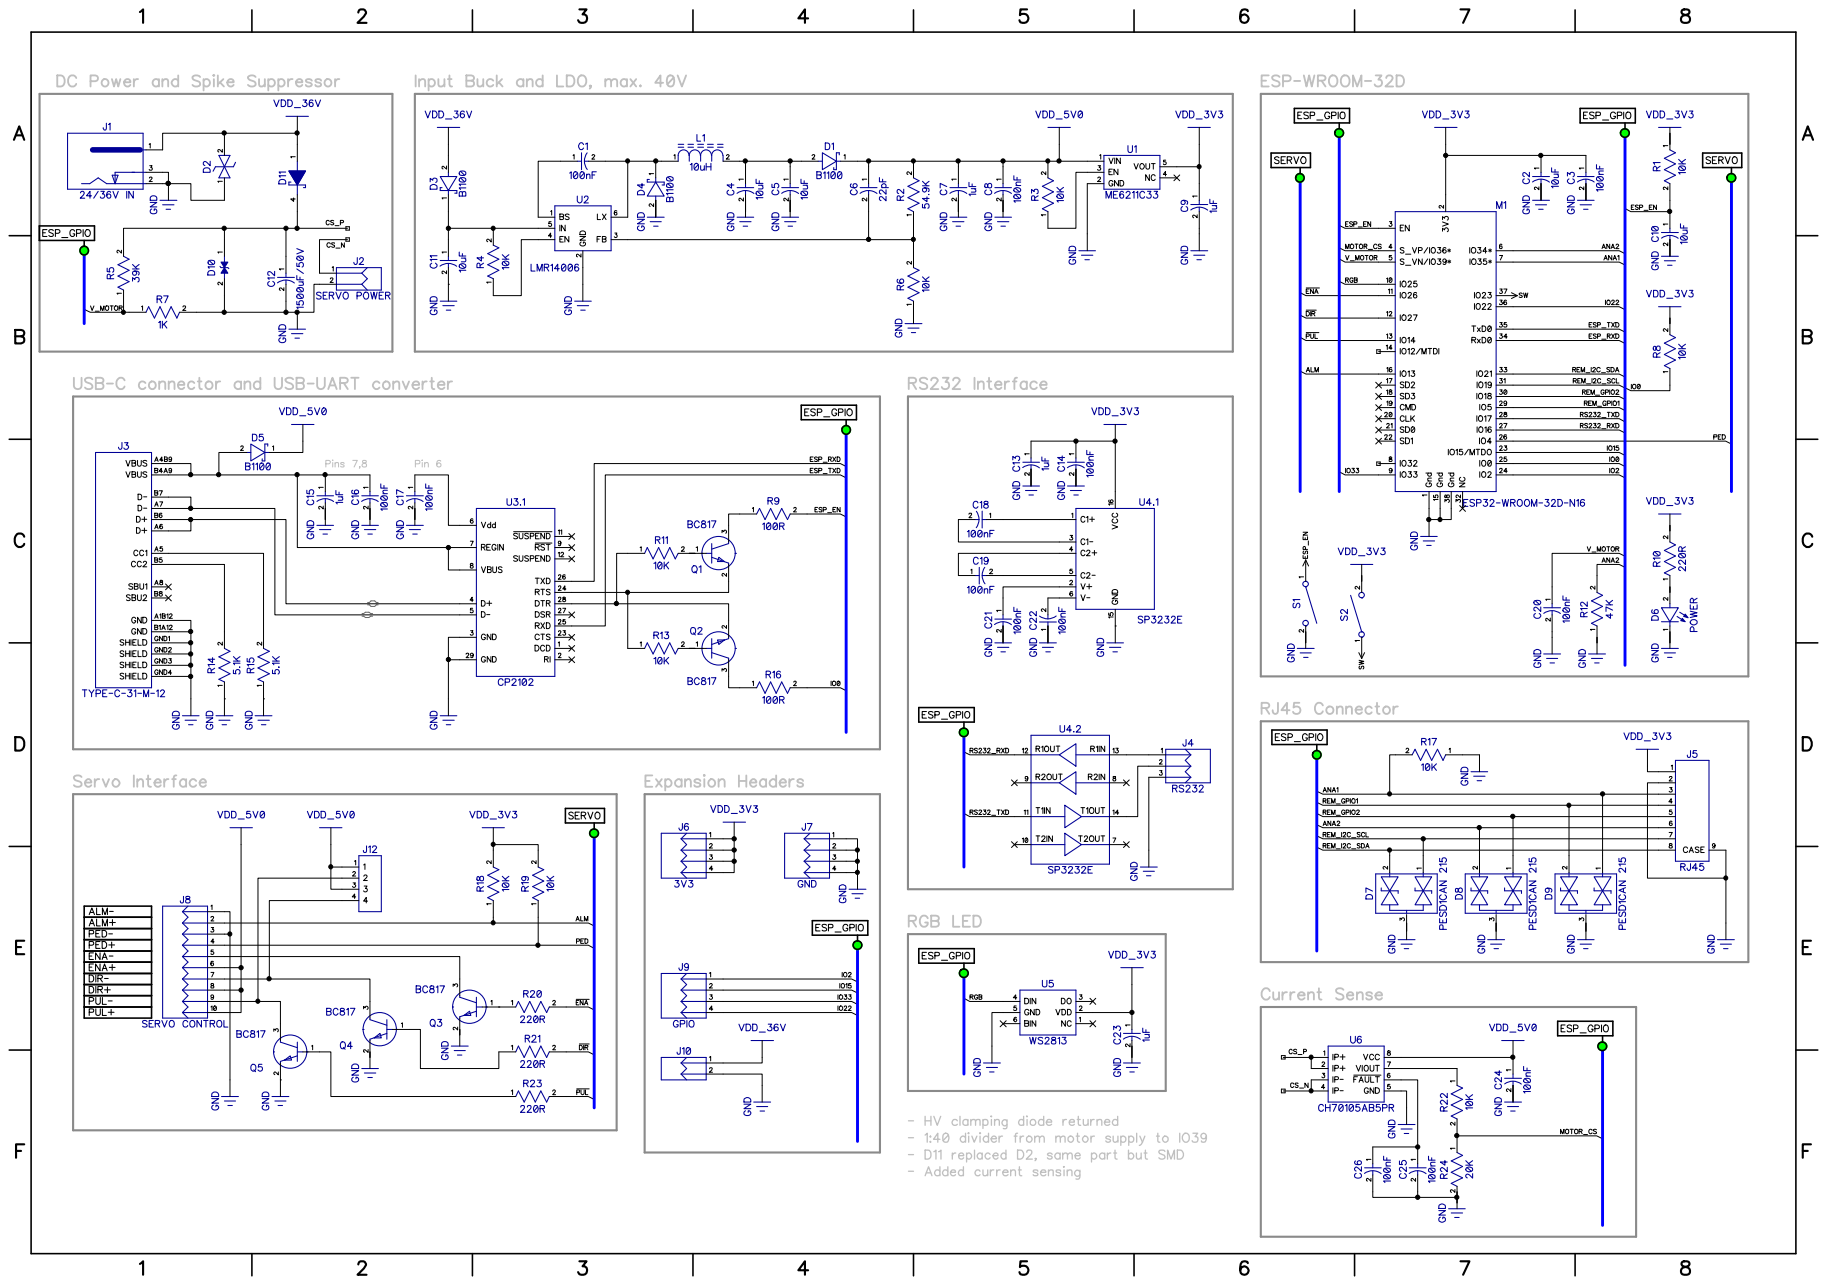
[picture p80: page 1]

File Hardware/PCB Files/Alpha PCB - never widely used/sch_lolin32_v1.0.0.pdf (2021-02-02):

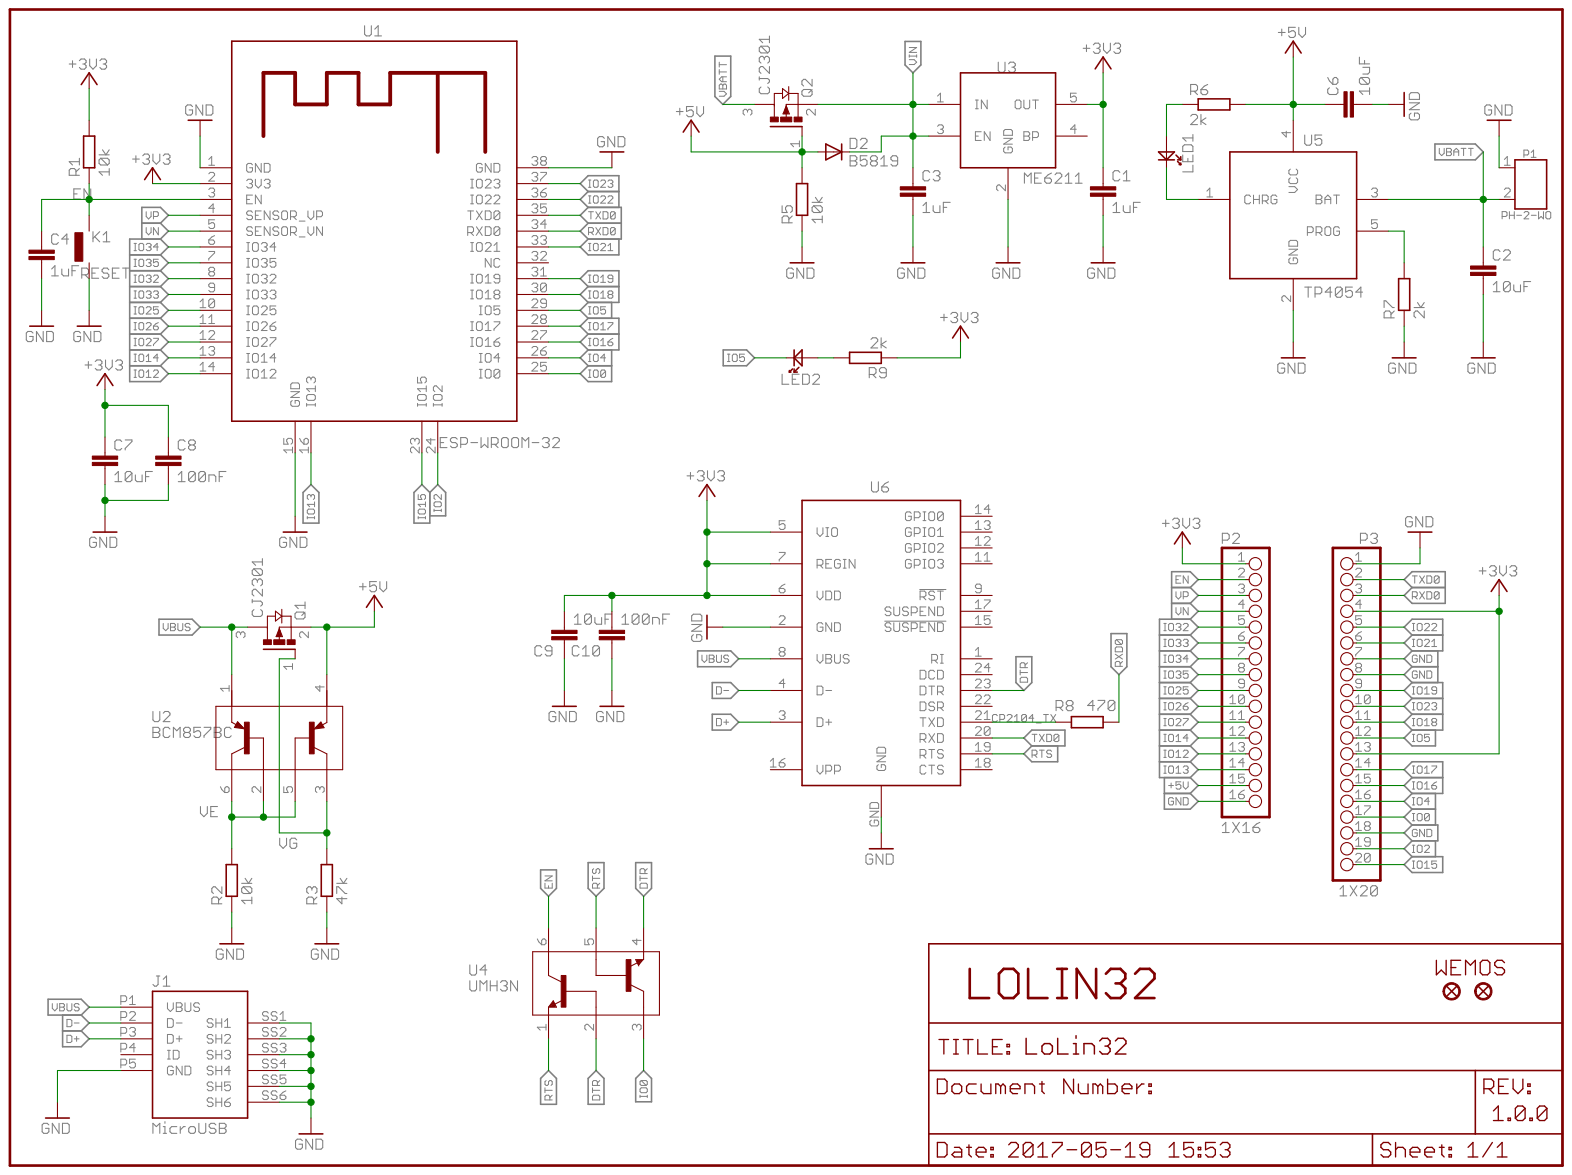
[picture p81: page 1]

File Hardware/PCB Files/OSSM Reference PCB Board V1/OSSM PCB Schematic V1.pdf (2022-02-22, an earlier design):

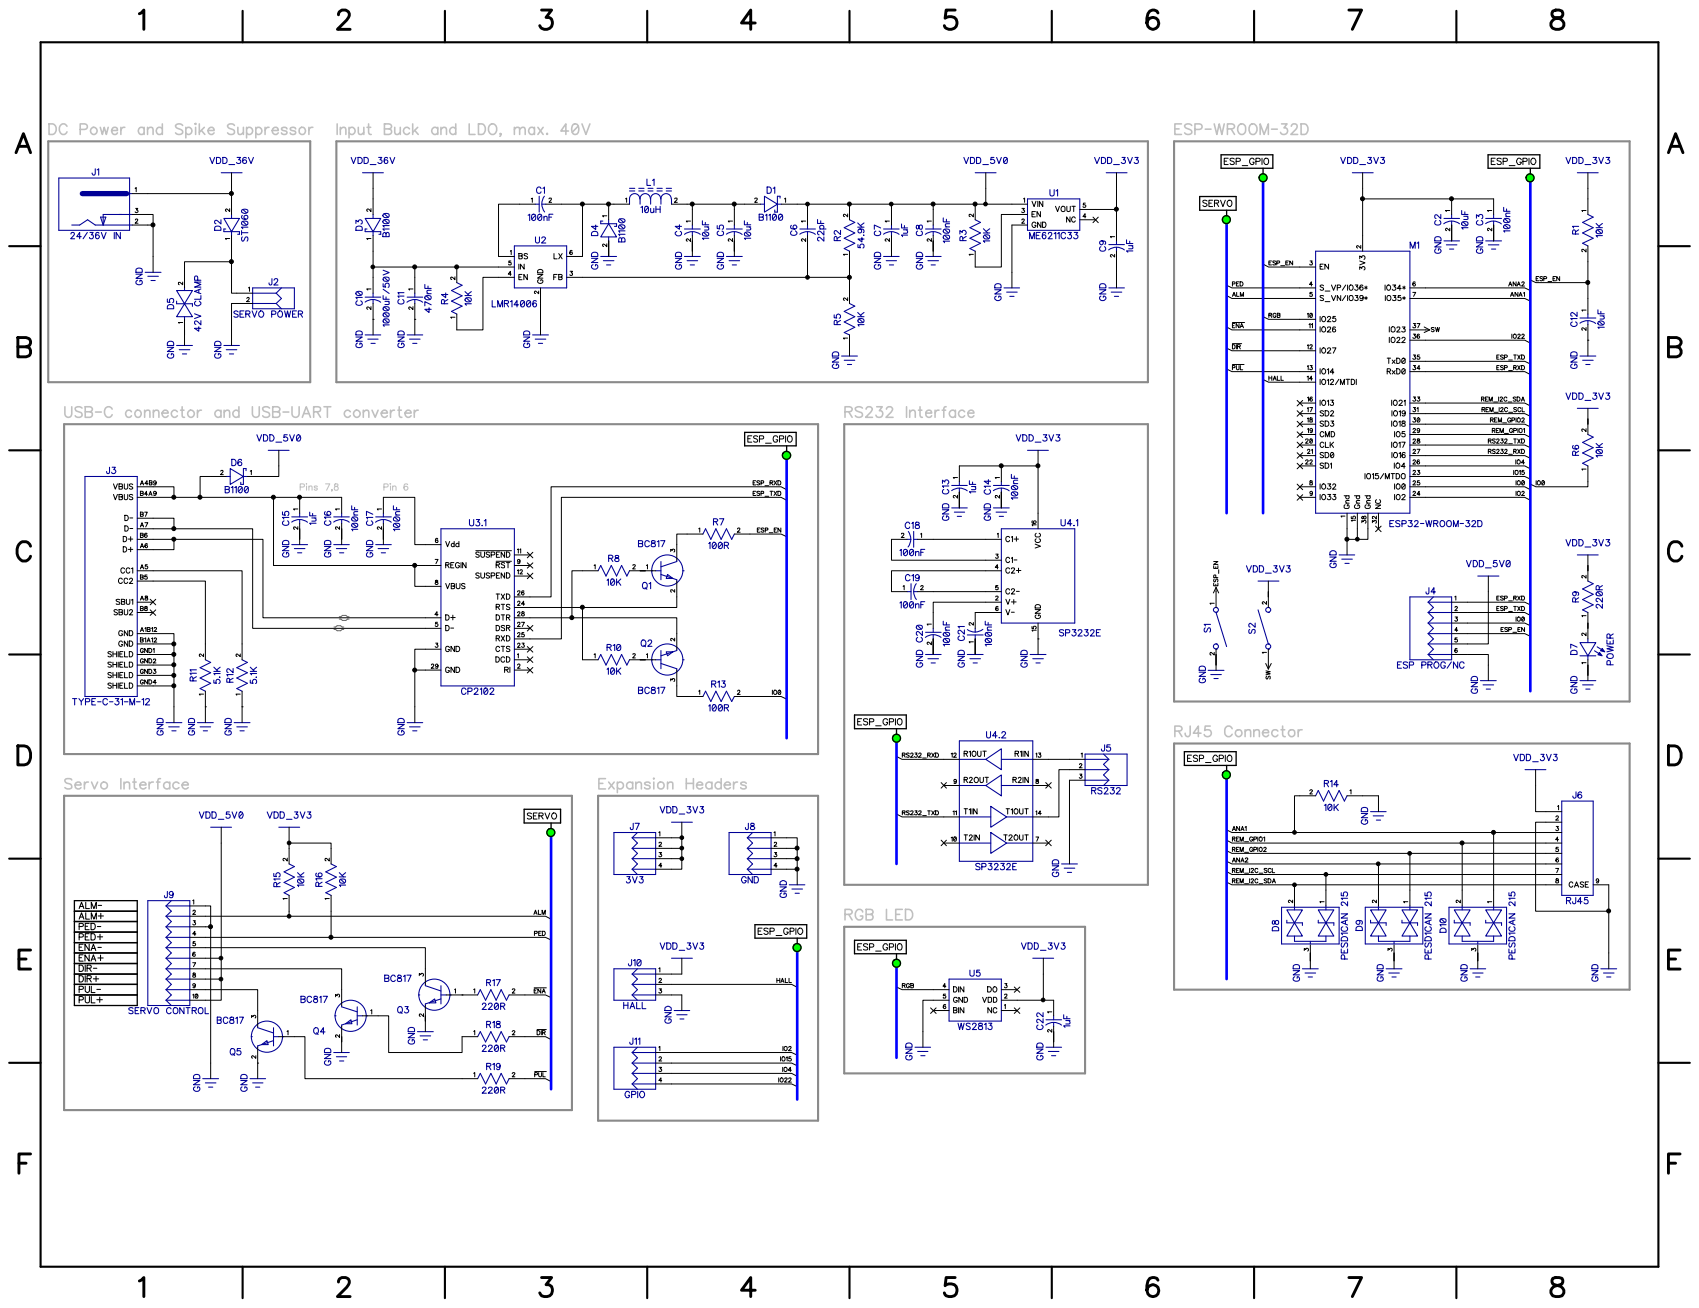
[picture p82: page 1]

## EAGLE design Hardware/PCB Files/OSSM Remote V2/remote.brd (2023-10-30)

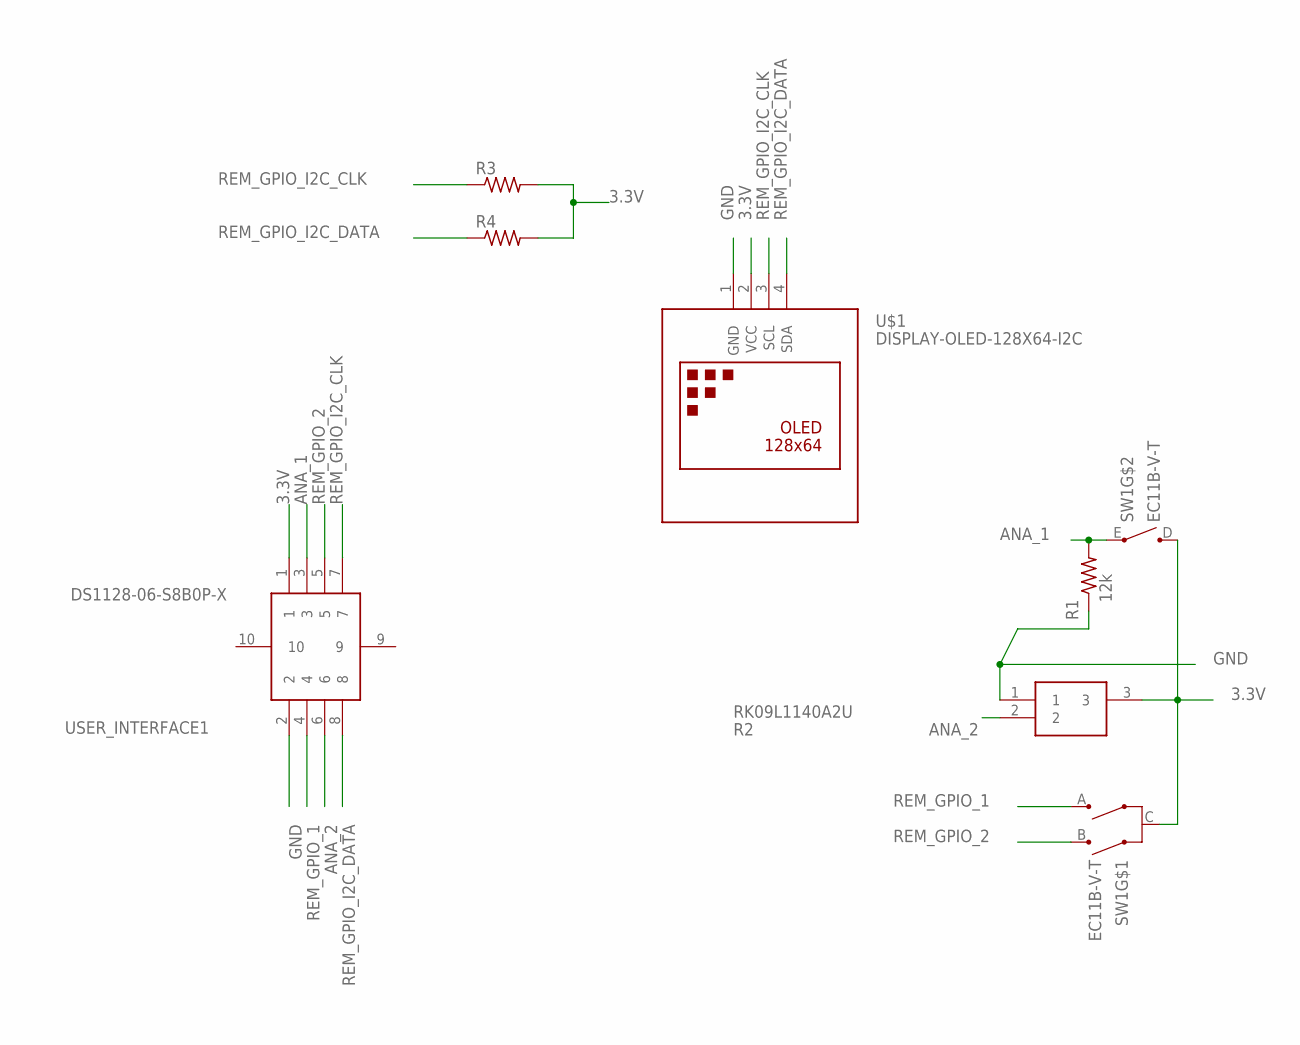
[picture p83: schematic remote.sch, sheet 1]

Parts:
R1: 12k; R0805
R2: RK09L1140A2U; RK09L1140A5E
R3, R4: R-US_R0805; R0805
SW1: EC11B-V-T; EC11B-V
U$1: DISPLAY-OLED-128X64-I2C
USER_INTERFACE1: DS1128-06-S8B0P-X; DS112806S8B0PX

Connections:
3.3V: R2.3, R3.2, R4.2, SW1.C, SW1.D, U$1.2 (VCC), USER_INTERFACE1.1
ANA_1: R1.2, SW1.E, USER_INTERFACE1.3
ANA_2: R2.2, USER_INTERFACE1.6
GND: R1.1, R2.1, U$1.1 (GND), USER_INTERFACE1.2
REM_GPIO_1: SW1.A, USER_INTERFACE1.4
REM_GPIO_2: SW1.B, USER_INTERFACE1.5
REM_GPIO_I2C_CLK: R3.1, U$1.3 (SCL), USER_INTERFACE1.7
REM_GPIO_I2C_DATA: R4.1, U$1.4 (SDA), USER_INTERFACE1.8

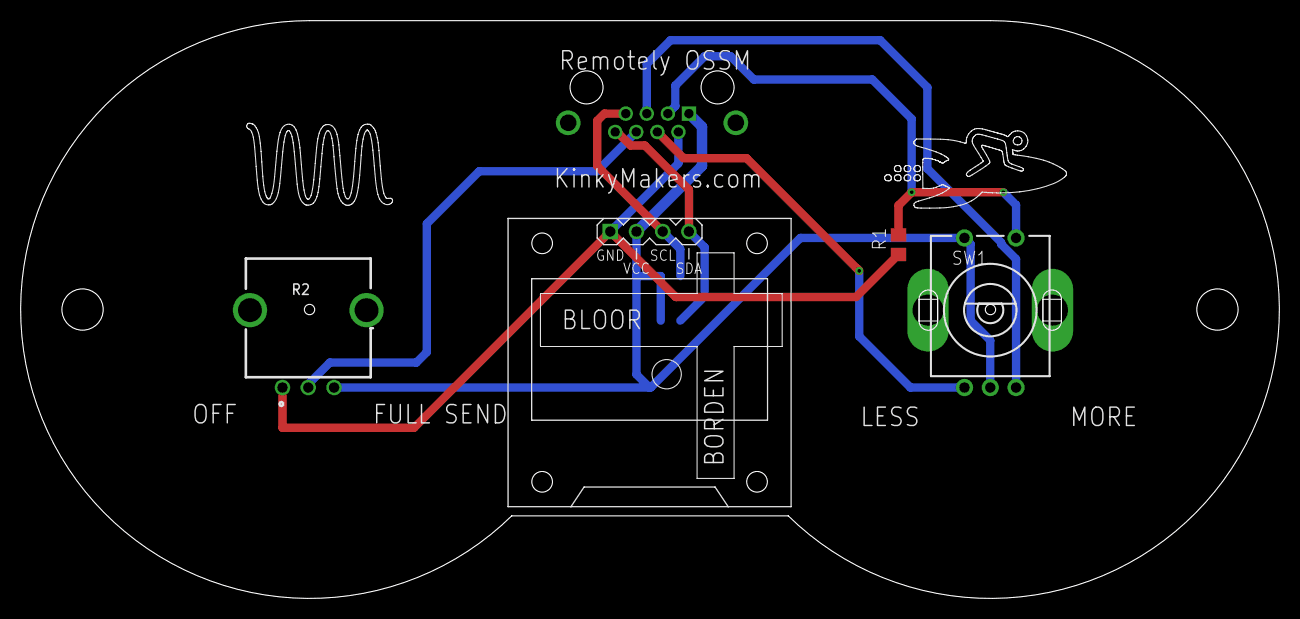
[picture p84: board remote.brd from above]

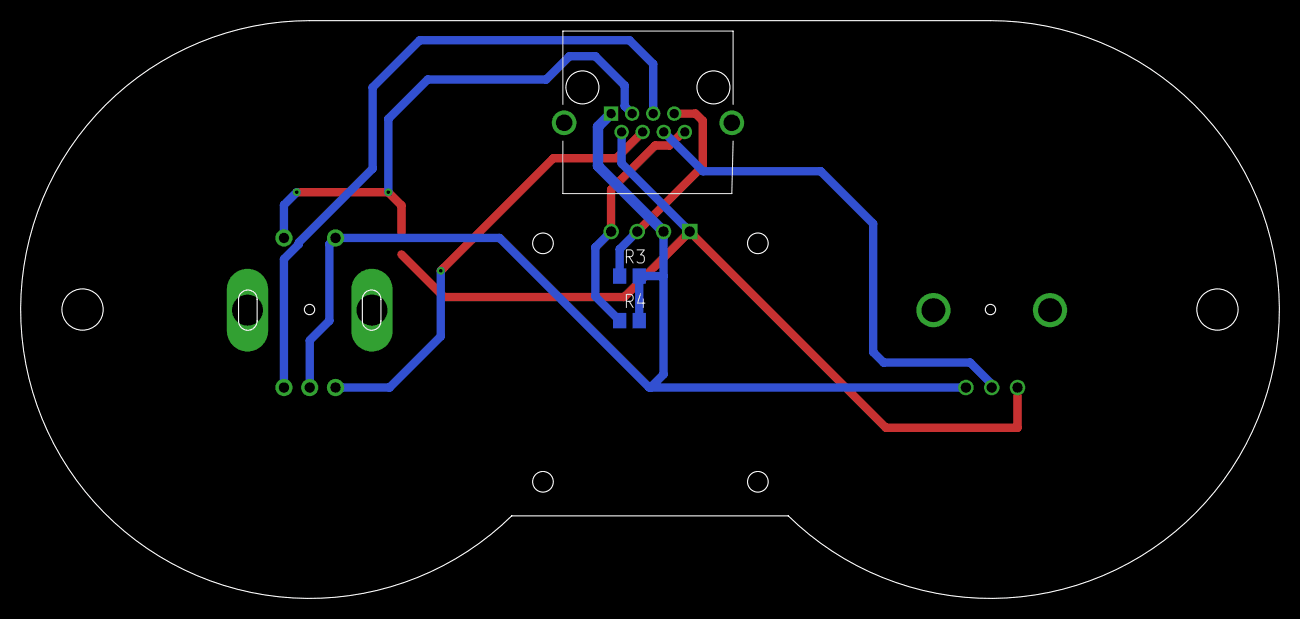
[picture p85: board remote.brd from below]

Board: 2 copper layers, 122.0 x 56.0 mm, 7 parts (3 on the bottom side), 8 nets.

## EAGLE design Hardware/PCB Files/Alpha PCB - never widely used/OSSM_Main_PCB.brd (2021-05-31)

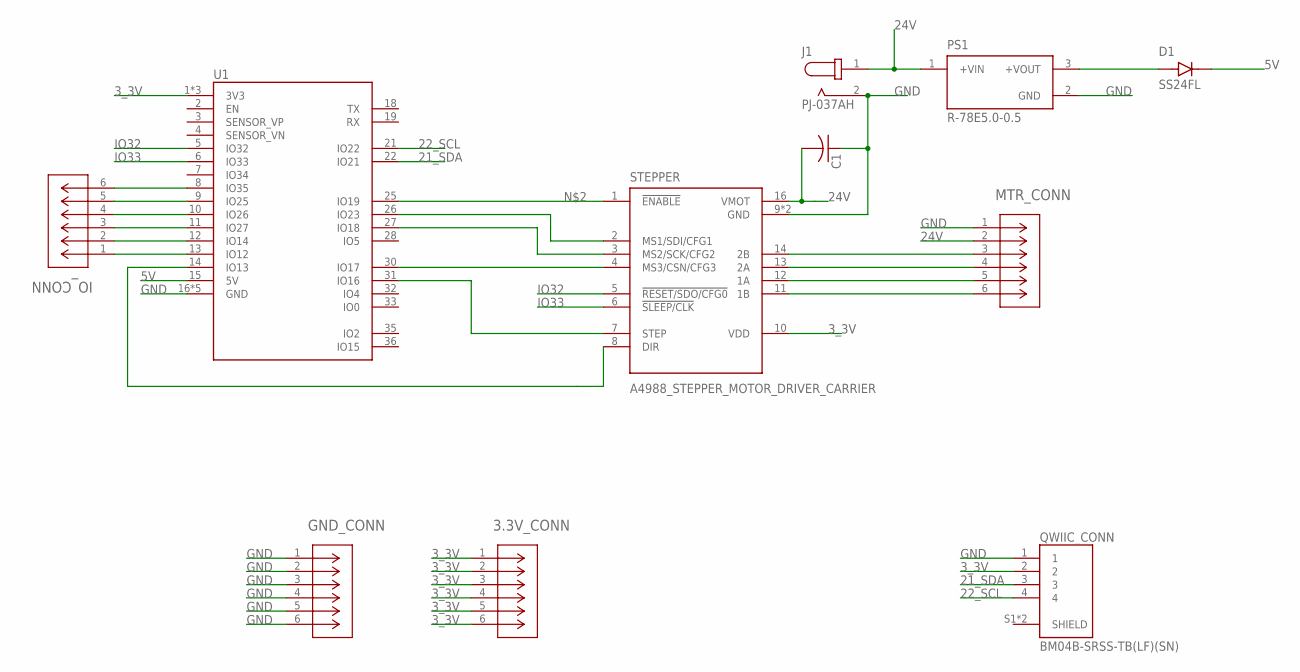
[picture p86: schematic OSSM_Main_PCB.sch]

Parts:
3.3V_CONN: 1792902; CONN_1792902_PXC
C1: C-US050-024X044; C050-024X044
D1: SS24FL; SODFL3617X108N
GND_CONN: 1792902; CONN_1792902_PXC
IO_CONN: 1792902; CONN_1792902_PXC
J1: PJ-037AH; CUI_PJ-037AH
MTR_CONN: 1792902; CONN_1792902_PXC
PS1: R-78E5.0-0.5; CONV_R-78E5.0-0.5
QWIIC_CONN: BM04B-SRSS-TB(LF)(SN); CONN_BM04B-SRSS-TB(LF)(SN)
STEPPER: A4988_STEPPER_MOTOR_DRIVER_CARRIER; MODULE_A4988_STEPPER_MOTOR_DRIVER_CARRIER
U1: LOLIN32_PRODUCTION

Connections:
3_3V: 3.3V_CONN.1, 3.3V_CONN.2, 3.3V_CONN.3, 3.3V_CONN.4, 3.3V_CONN.5, 3.3V_CONN.6, QWIIC_CONN.2, STEPPER.10 (VDD), U1.1 (3V3), U1.20 (3V3), U1.29 (3V3)
5V: D1.C, U1.15 (5V)
21_SDA: QWIIC_CONN.3, U1.22 (IO21)
22_SCL: QWIIC_CONN.4, U1.21 (IO22)
24V: C1.2, J1.1, MTR_CONN.2, PS1.1 (+VIN), STEPPER.16 (VMOT)
GND: C1.1, GND_CONN.1, GND_CONN.2, GND_CONN.3, GND_CONN.4, GND_CONN.5, GND_CONN.6, J1.2, MTR_CONN.1, PS1.2 (GND), QWIIC_CONN.1, STEPPER.9 (GND), STEPPER.15 (GND), U1.16 (GND), U1.17 (GND), U1.23 (GND), U1.24 (GND), U1.34 (GND)
IO32: STEPPER.5 (!RESET/SDO/CFG0), U1.5 (IO32)
IO33: STEPPER.6 (!SLEEP/CLK), U1.6 (IO33)
unnamed: D1.A, PS1.3 (+VOUT)
unnamed: STEPPER.1 (!ENABLE), U1.25 (IO19)
unnamed: STEPPER.2 (MS1/SDI/CFG1), U1.26 (IO23)
unnamed: STEPPER.3 (MS2/SCK/CFG2), U1.27 (IO18)
unnamed: STEPPER.4 (MS3/CSN/CFG3), U1.30 (IO17)
unnamed: STEPPER.7 (STEP), U1.31 (IO16)
unnamed: STEPPER.8 (DIR), U1.14 (IO13)
unnamed: MTR_CONN.6, STEPPER.11 (1B)
unnamed: MTR_CONN.5, STEPPER.12 (1A)
unnamed: MTR_CONN.4, STEPPER.13 (2A)
unnamed: MTR_CONN.3, STEPPER.14 (2B)
unnamed: IO_CONN.1, U1.13 (IO12)
unnamed: IO_CONN.2, U1.12 (IO14)
unnamed: IO_CONN.3, U1.11 (IO27)
unnamed: IO_CONN.4, U1.10 (IO26)
unnamed: IO_CONN.5, U1.9 (IO25)
unnamed: IO_CONN.6, U1.8 (IO35)

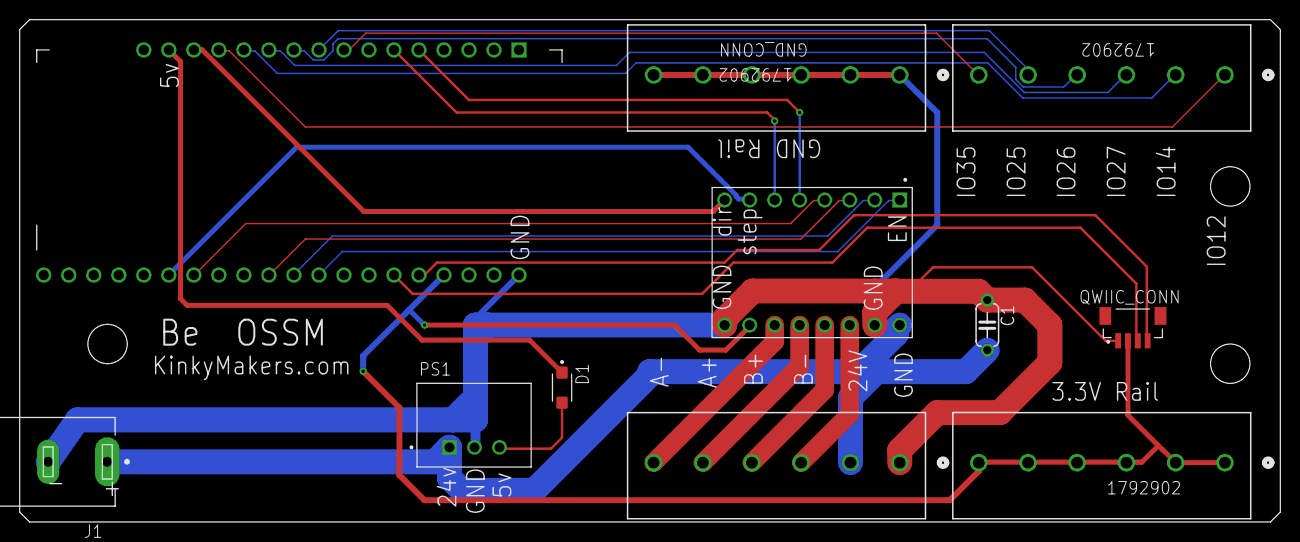
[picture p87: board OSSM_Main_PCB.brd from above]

Board: 2 copper layers, 128.0 x 51.0 mm, 11 parts (0 on the bottom side), 25 nets.

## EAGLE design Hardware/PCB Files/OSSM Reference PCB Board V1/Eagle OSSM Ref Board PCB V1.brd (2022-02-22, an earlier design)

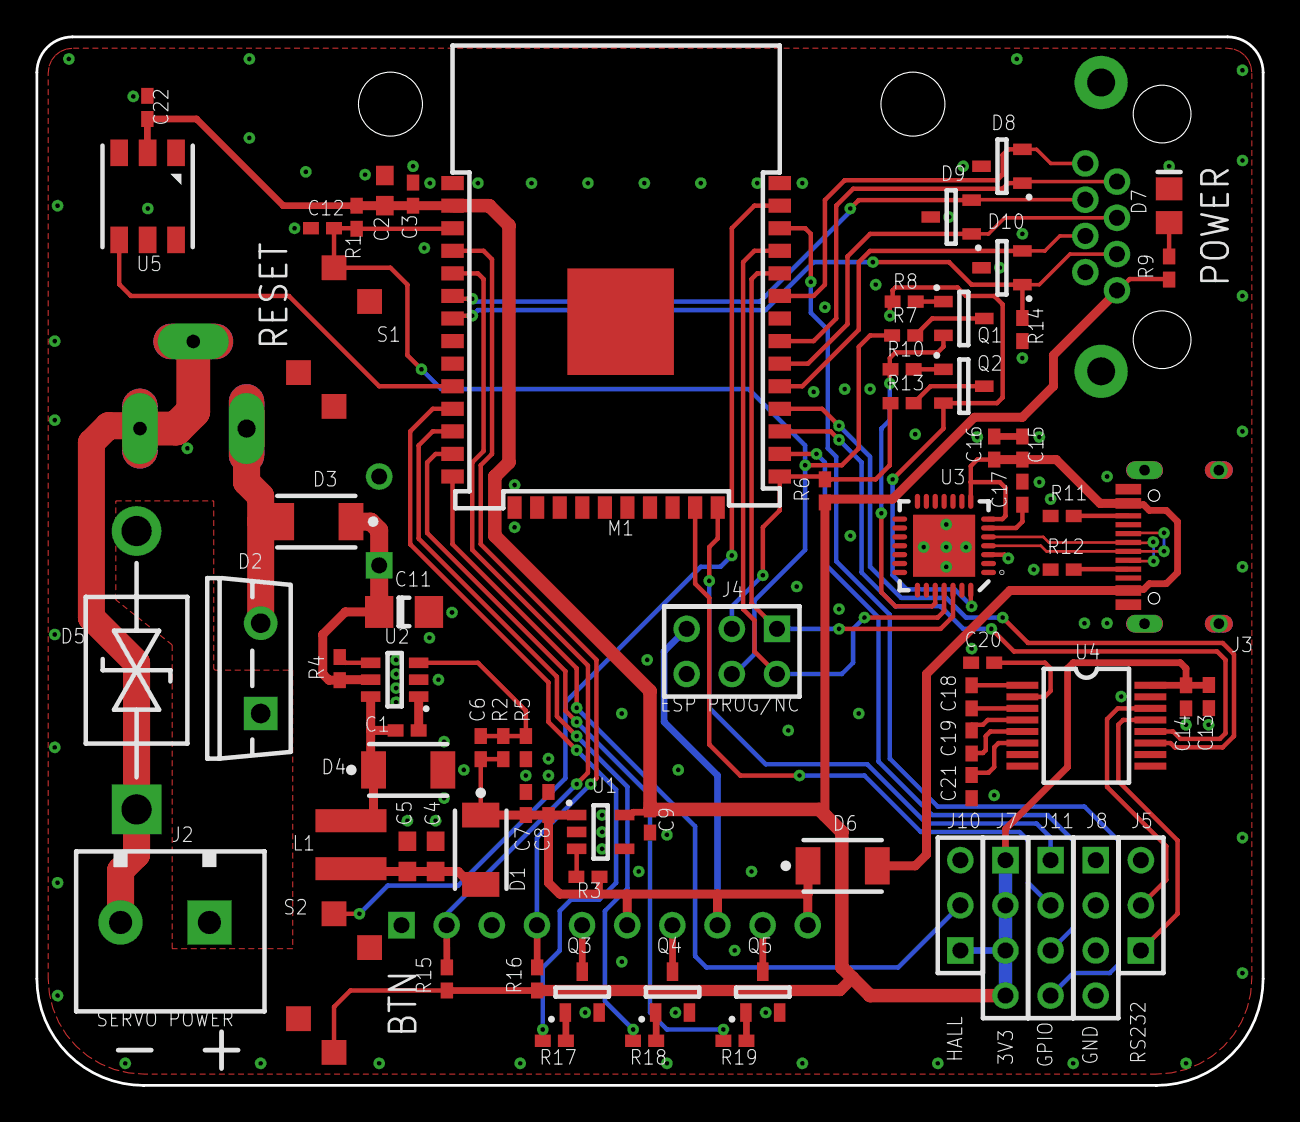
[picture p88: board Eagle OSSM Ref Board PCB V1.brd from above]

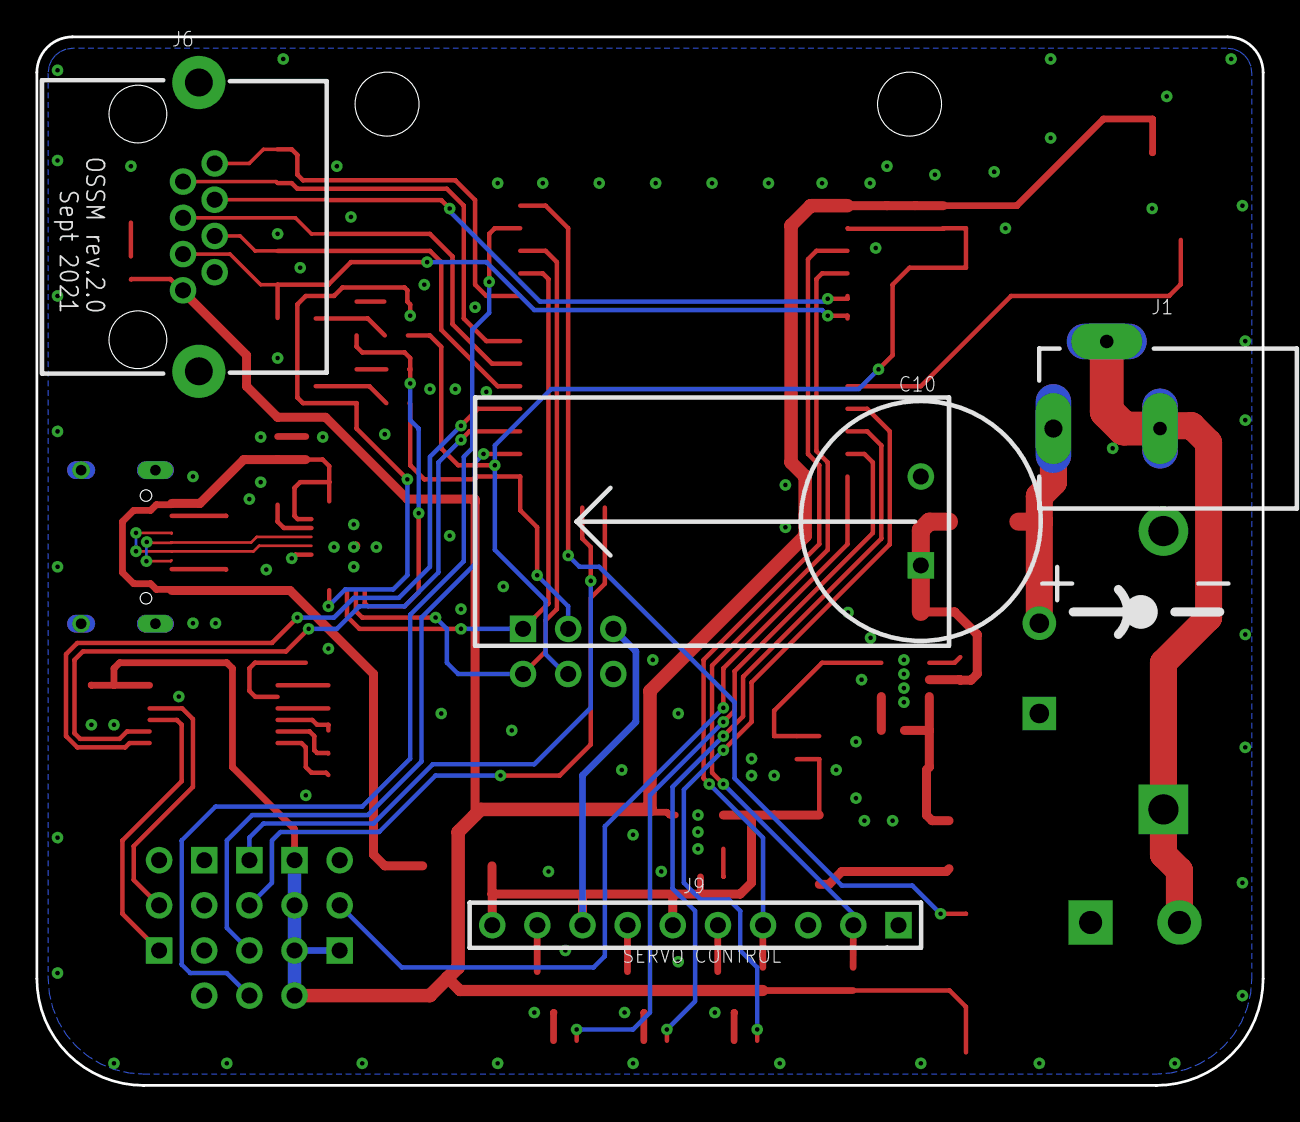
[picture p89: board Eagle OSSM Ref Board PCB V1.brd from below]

Board: 2 copper layers, 69.0 x 59.0 mm, 88 parts (4 on the bottom side), 63 nets.

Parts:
C1, C3, C8, C14, C16, C17, C18, C19, C20, C21: 100nF; CAP_0402
C2, C4, C5: 10uF; CAP_0603
C6: 22pF; CAP_0402
C7, C9, C13, C15, C22: 1uF; CAP_0402
C10: 1000uF/50V; CAPR-5/13.5h22
C11: 470nF; CAP_1206
C12: 10uF; CAP_0402
D1: B1100; SMA
D2: ST1060; TO-220FP-2
D3, D4, D6: B1100; SMA_D3
D5: 42V CLAMP; DO-201AD
D7: POWER; DIO_0805
D8, D9, D10: PESD1CAN 215; SOT23
J1: 24/36V IN; RAPC722X
J2: SERVO POWER; TB-1x2/5/11x9/Sc_H
J3: TYPE-C-31-M-12
J4: ESP PROG/NC; HDR-2x3
J5: RS232; HDR-1x3
J6: RJ45; DS1128-06-S8B0P-X
J7: 3V3; HDR-1x4
J8: GND; HDR-1x4
J9: SERVO CONTROL; HDR-1x10
J10: HALL; HDR-1x3
J11: GPIO; HDR-1x4
Keepout_1: 1; ROUTE_KEEPOUT_1
Keepout_2: 2; ROUTE_KEEPOUT_2
Keepout_3: 3; ROUTE_KEEPOUT_3
Keepout_4: 4; ROUTE_KEEPOUT_4
Keepout_5: 5; ROUTE_KEEPOUT_5
Keepout_6: 6; ROUTE_KEEPOUT_6
Keepout_7: 7; ROUTE_KEEPOUT_7
Keepout_8: 8; ROUTE_KEEPOUT_8
Keepout_9: 9; ROUTE_KEEPOUT_9
Keepout_10: 10; ROUTE_KEEPOUT_10
Keepout_11: 11; ROUTE_KEEPOUT_11
Keepout_12: 12; ROUTE_KEEPOUT_12
L1: 10uH; VLS4012E
M1: ESP32-WROOM-32D; ESP-WROOM-32
Q1, Q2, Q3, Q4, Q5: BC817; SOT23
R1, R3, R4, R5, R6, R8, R10, R14, R15, R16: 10K; RES_0402
R2: 54.9K; RES_0402
R7, R13: 100R; RES_0402
R9, R17, R18, R19: 220R; RES_0402
R11, R12: 5.1K; RES_0402
S1, S2: K2-1107ST-A4SW-06; Sunrom_1P1T_switch
U1: ME6211C33; SOT23-5
U2: LMR14006; SOT23-6
U3: CP2102; QFN-28/5x5x0.5
U4: SP3232E; SSOP-16
U5: WS2813

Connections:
!DIR: M1.12, R18.2
!ENA: M1.11, R17.2
!PUL: M1.13, R19.2
ALM: J9.2, M1.5, R15.1
ANA1: D10.1, J6.3, M1.7, R14.2
ANA2: D9.2, J6.6, M1.6
ESP_EN: C12.1, J4.4, M1.3, R1.2, R7.2, S1.1
ESP_RXD: J4.1, M1.34, U3.26
ESP_TXD: J4.2, M1.35, U3.25
GND: C2.2, C3.2, C4.2, C5.2, C7.2, C8.2, C9.2, C10.2, C11.2, C12.2, C13.2, C14.2, C15.2, C16.2, C17.2, C20.2, C21.1, C22.2, D4.2, D5.1, D7.1, D8.3, D9.3, D10.3, J1.2, J1.3, J2.2, J3.A1B12, J3.B1A12, J3.GND1, J3.GND2, J3.GND3, J3.GND4, J4.6, J5.3, J6.2, J6.9, J6.10, J8.1, J8.2, J8.3, J8.4, J9.1, J9.3, J10.3, M1.1, M1.15, M1.38, M1.39, Q3.2, Q4.2, Q5.2, R5.1, R11.1, R12.1, R14.1, S1.2, S1.3, S1.4, U1.2, U2.2, U3.3, U3.29, U4.15, U5.5
HALL: J10.2, M1.14
IO0: J4.3, M1.25, R6.1, R13.2
IO2: J11.1, M1.24
IO4: J11.3, M1.26
IO15: J11.2, M1.23
IO22: J11.4, M1.36
Net_0: D2.2, D3.2, J1.1
Net_3: C4.1, C5.1, D1.2, L1.2
Net_6: Q1.1, R8.2
Net_12: C17.1, U3.6
Net_23: Q2.1, R10.2
Net_24: R3.1, U1.3
Net_25: Q1.2, R10.1, U3.24
Net_26: Q2.2, R8.1, U3.28
Net_32: R4.1, U2.4
Net_33: C1.1, U2.1
Net_34: C1.2, D4.1, L1.1, U2.6
Net_35: C6.2, R2.1, R5.2, U2.3
Net_37: J9.9, Q5.3
Net_38: J9.7, Q4.3
Net_39: J9.5, Q3.3
Net_40: Q3.1, R17.1
Net_41: Q4.1, R18.1
Net_42: Q5.1, R19.1
Net_47: C18.1, U4.1
Net_48: C18.2, U4.3
Net_49: C19.1, U4.4
Net_50: C19.2, U4.5
Net_52: J5.1, U4.13
Net_53: J5.2, U4.14
Net_54: C20.1, U4.2
Net_60: D2.1, D5.2, J2.1
Net_61: C21.2, U4.6
Net_62: D7.2, R9.1
Net_74: J3.B5, R11.2
Net_75: J3.A5, R12.2
Net_76: Q2.3, R13.1
Net_77: Q1.3, R7.1
PED: J9.4, M1.4, R16.1
REM_GPIO1: D10.2, J6.4, M1.29
REM_GPIO2: D9.1, J6.5, M1.30
REM_I2C_SCL: D8.1, J6.7, M1.31
REM_I2C_SDA: D8.2, J6.8, M1.33
RGB: M1.10, U5.4
RS232_RXD: M1.27, U4.12
RS232_TXD: M1.28, U4.11
SW: M1.37, S2.1
USB_D_N: J3.A7, J3.B7, U3.5
USB_D_P: J3.A6, J3.B6, U3.4
VDD_3V3: C2.1, C3.1, C9.1, C13.1, C14.1, C22.1, J6.1, J7.1, J7.2, J7.3, J7.4, J10.1, M1.2, R1.1, R6.2, R9.2, R15.2, R16.2, S2.2, U1.5, U4.16, U5.2
VDD_5V0: C6.1, C7.1, C8.1, D1.1, D6.1, J4.5, J9.6, J9.8, J9.10, R2.2, R3.2, U1.1
VDD_36V: C10.1, C11.1, D3.1, R4.2, U2.5
VDD_USB: C15.1, C16.1, D6.2, J3.A4B9, J3.B4A9, U3.7, U3.8

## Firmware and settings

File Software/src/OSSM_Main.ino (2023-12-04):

#include <Arduino.h>          // Basic Needs
#include <ArduinoJson.h>      // Needed for the Bubble APP
#include <ESP_FlexyStepper.h> // Current Motion Control
#include <Encoder.h>          // Used for the Remote Encoder Input
#include <HTTPClient.h>       // Needed for the Bubble APP
#include <WiFiManager.h>      // Used to provide easy network connection  https://github.com/tzapu/WiFiManager
#include <Wire.h>             // Used for i2c connections (Remote OLED Screen)

#include "OSSM_Config.h" // START HERE FOR Configuration
#include "OSSM_PinDef.h" // This is where you set pins specific for your board
#include "OssmUi.h"      // Separate file that helps contain the OLED screen functions
#include "Stroke_Engine_Helper.h"
#include "Utilities.h" // Utility helper functions - wifi update and homing

// Homing
volatile bool g_has_not_homed = true;
bool REMOTE_ATTACHED = false;

// OSSM name setup
const char *ossmId = "OSSM1";
volatile int encoderButtonPresses = 0; // increment for each click
volatile long lastEncoderButtonPressMillis = 0;

IRAM_ATTR void encoderPushButton()
{
    // TODO: Toggle position mode
    // g_encoder.write(0);       // Reset on Button Push
    // ossm.g_ui.NextFrame();         // Next Frame on Button Push

    // debounce check
    long currentTime = millis();
    if ((currentTime - lastEncoderButtonPressMillis) > 200)
    {
        // run interrupt if not run in last 50ms
        encoderButtonPresses++;
        lastEncoderButtonPressMillis = currentTime;
    }
}

// Current command state
// volatile float strokePercentage = 0;
// volatile float ossm.speedPercentage = 0;
// volatile float deceleration = 0;

// Create tasks for checking pot input or web server control, and task to handle
// planning the motion profile (this task is high level only and does not pulse
// the stepper!)
TaskHandle_t wifiTask = nullptr;
TaskHandle_t getInputTask = nullptr;
TaskHandle_t motionTask = nullptr;
TaskHandle_t estopTask = nullptr;
TaskHandle_t oledTask = nullptr;

// Declarations
// TODO: Document functions
// void setLedRainbow(CRGB leds[]);
void getUserInputTask(void *pvParameters);
void motionCommandTask(void *pvParameters);
void wifiConnectionTask(void *pvParameters);

// create the OSSM hardware object
OSSM ossm;

///////////////////////////////////////////
////
////  VOID SETUP -- Here's where it's hiding
////
///////////////////////////////////////////

void setup()
{
    ossm.startLeds();
    Serial.begin(115200);
    LogDebug("\n Starting");
    pinMode(ENCODER_SWITCH, INPUT_PULLDOWN); // Rotary Encoder Pushbutton
    attachInterrupt(digitalPinToInterrupt(ENCODER_SWITCH), encoderPushButton, RISING);

    ossm.setup();

    // start the WiFi connection task so we can be doing something while homing!
    xTaskCreatePinnedToCore(wifiConnectionTask,   /* Task function. */
                            "wifiConnectionTask", /* name of task. */
                            10000,                /* Stack size of task */
                            NULL,                 /* parameter of the task */
                            1,                    /* priority of the task */
                            &wifiTask,            /* Task handle to keep track of created task */
                            0);                   /* pin task to core 0 */
    delay(100);

    ossm.findHome();

    ossm.setRunMode();

    // Kick off the http and motion tasks - they begin executing as soon as they
    // are created here! Do not change the priority of the task, or do so with
    // caution. RTOS runs first in first out, so if there are no delays in your
    // tasks they will prevent all other code from running on that core!
    xTaskCreatePinnedToCore(getUserInputTask,   /* Task function. */
                            "getUserInputTask", /* name of task. */
                            10000,              /* Stack size of task */
                            NULL,               /* parameter of the task */
                            1,                  /* priority of the task */
                            &getInputTask,      /* Task handle to keep track of created task */
                            0);                 /* pin task to core 0 */
    delay(100);
    xTaskCreatePinnedToCore(motionCommandTask,   /* Task function. */
                            "motionCommandTask", /* name of task. */
                            20000,               /* Stack size of task */
                            NULL,                /* parameter of the task */
                            1,                   /* priority of the task */
                            &motionTask,         /* Task handle to keep track of created task */
                            0);                  /* pin task to core 0 */

    delay(100);
    ossm.g_ui.UpdateMessage("OSSM Ready to Play");
} // Void Setup()

///////////////////////////////////////////
////
////
////   VOID LOOP - Hides here
////
////
///////////////////////////////////////////

void loop()
{
    switch (ossm.rightKnobMode)
    {
        case MODE_STROKE:
            ossm.g_ui.UpdateState("STROKE", static_cast<int>(ossm.speedPercentage),
                                  static_cast<int>(ossm.strokePercentage + 0.5f));
            break;
        case MODE_DEPTH:
            ossm.g_ui.UpdateState("DEPTH", static_cast<int>(ossm.speedPercentage),
                                  static_cast<int>(ossm.depthPercentage + 0.5f));
            break;
        case MODE_SENSATION:
            ossm.g_ui.UpdateState("SENSTN", static_cast<int>(ossm.speedPercentage),
                                  static_cast<int>(ossm.sensationPercentage + 0.5f));
            break;
        case MODE_PATTERN:
            ossm.g_ui.UpdateState("PATTRN", static_cast<int>(ossm.speedPercentage),
                                  ossm.strokePattern * 100 / (ossm.strokePatternCount - 1));
            break;
    }
    ossm.g_ui.UpdateScreen();

    // debug
    static bool is_connected = false;
    if (!is_connected && ossm.g_ui.DisplayIsConnected())
    {
        LogDebug("Display Connected");
        is_connected = true;
    }
    else if (is_connected && !ossm.g_ui.DisplayIsConnected())
    {
        LogDebug("Display Disconnected");
        is_connected = false;
    }
}

///////////////////////////////////////////
////
////
////  freeRTOS multitasking
////
////
///////////////////////////////////////////

void wifiConnectionTask(void *pvParameters)
{
    ossm.wifiConnectOrHotspotNonBlocking();
}

// Task to read settings from server - only need to check this when in WiFi
// control mode
void getUserInputTask(void *pvParameters)
{
    float targetSpeedMmPerSecond = 0;
    float targetAccelerationMm = 0;
    float previousSpeedPercentage = 0;
    for (;;) // tasks should loop forever and not return - or will throw error in
             // OS
    {
        // LogDebug("Speed: " + String(ossm.speedPercentage) + "\% Stroke: " + String(ossm.strokePercentage) +
        //          "\% Distance to target: " + String(ossm.stepper.getDistanceToTargetSigned()) + " steps?");

        ossm.updateAnalogInputs();
        ossm.handleStopCondition();

        if (digitalRead(WIFI_CONTROL_TOGGLE_PIN) == HIGH) // TODO: check if wifi available and handle gracefully
        {
            ossm.enableWifiControl();
        }
        else
        {
            if (ossm.wifiControlActive == true)
            {
                // this is a transition to local control, we should tell the server it cannot control

                ossm.setInternetControl(false);
            }
        }

        // We should scale these values with initialized settings not hard coded
        // values!
        if (ossm.speedPercentage > ossm.commandDeadzonePercentage)
        {
            targetSpeedMmPerSecond = ossm.maxSpeedMmPerSecond * ossm.speedPercentage / 100.0;
            if ((ossm.speedPercentage - previousSpeedPercentage) > 30)
            {
                targetSpeedMmPerSecond =
                    0.5 * (ossm.speedPercentage + previousSpeedPercentage) * ossm.maxSpeedMmPerSecond / 100.0;
            }
            targetAccelerationMm =
                ossm.maxSpeedMmPerSecond * ossm.speedPercentage * ossm.speedPercentage / ossm.accelerationScaling;

            ossm.stepper.setAccelerationInMillimetersPerSecondPerSecond(targetAccelerationMm);
            if (targetSpeedMmPerSecond > ossm.stepper.getCurrentVelocityInMillimetersPerSecond())
            { // we are speeding up, we need to increase deccel rate!
                ossm.stepper.setDecelerationInMillimetersPerSecondPerSecond(targetAccelerationMm);
            }

            ossm.stepper.setSpeedInMillimetersPerSecond(targetSpeedMmPerSecond);

            // If target speed is lower than current, we do not update deccel as setting a low decel when going from
            // high to low speed causes the motor to travel a long distance before slowing.
        }
        previousSpeedPercentage = ossm.speedPercentage;
        vTaskDelay(50); // let other code run!
    }
}

void motionCommandTask(void *pvParameters)
{
    for (;;) // tasks should loop forever and not return - or will throw error in
             // OS
    {
        switch (ossm.activeRunMode)
        {
            case ossm.simpleMode:
                ossm.runPenetrate();
                break;

            case ossm.strokeEngineMode:
                ossm.runStrokeEngine();
                break;
        }
    }
}

// float getAnalogVoltage(int pinNumber, int samples){

// }

// void setLedRainbow(CRGB leds[])
// {
//     // int power = 250;

//     for (int hueShift = 0; hueShift < 350; hueShift++)
//     {
//         int gHue = hueShift % 255;
//         fill_rainbow(leds, NUM_LEDS, gHue, 25);
//         FastLED.show();
//         delay(4);
//     }
// }

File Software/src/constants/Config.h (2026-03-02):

#ifndef OSSM_SOFTWARE_CONFIG_H
#define OSSM_SOFTWARE_CONFIG_H

#include <U8g2lib.h>

/**
    Default Config for OSSM - Reference board users should tweak UserConfig to
   match their personal build.

    //TODO: restore user overrides with a clever null coalescing operator
*/
namespace Config {

    /**
            Motion System Config
    */
    namespace Driver {
        // Max speed of the device
        constexpr float maxRPM = 1500.0f;
        // Number of teeth the pulley that is attached to the servo/stepper shaft has.
        constexpr float pulleyToothCount = 20.0f;
        // Set to your belt pitch (Distance between two teeth on the belt) (E.g.
        // GT2 belt has 2mm tooth pitch)
        constexpr float beltPitchMm = 2.0f;
        // Top linear speed of the device.
        constexpr float motorStepPerRevolution = 800.0f;
        // Top acceleration of the device in mm/s/s
        constexpr float maxAcceleration = 50000.0f;
        // Number of steps to move the arm 1mm
        constexpr float maxSpeedMmPerSecond = maxRPM / 60.0 * pulleyToothCount * beltPitchMm;
        // This should match the step/rev of your stepper or servo.
        // N.b. the iHSV57 has a table on the side for setting the DIP switches
        // to your preference.
        constexpr float stepsPerMM = motorStepPerRevolution / (pulleyToothCount * beltPitchMm);
        // This is the measured current that use to infer when the device has
        // reached the end of its stroke. during "Homing".
        constexpr float sensorlessCurrentLimit = 6.0f;

        namespace Operator {
            // Define user-defined literal for unsigned integer values
            constexpr long long operator"" _mm(unsigned long long x) {
                return x * stepsPerMM;
            }

            // Define user-defined literal for floating-point values
            constexpr long double operator"" _mm(long double x) {
                return x * stepsPerMM;
            }
        }

        using namespace Operator;

        // This is in millimeters, and is what's used to define how much of
        // your rail is usable.
        // The absolute max your OSSM would have is the distance between the
        // belt attachments subtract the linear block holder length (75mm on
        // OSSM) Recommended to also subtract e.g. 20mm to keep the backstop
        // well away from the device.
        constexpr float maxStrokeSteps = 500.0_mm;

        // If the stroke length is less than this value, then the stroke is
        // likely the result of a poor homing.
        constexpr float minStrokeLengthMm = 50.0_mm;

        // Applied offset after homing process.
        constexpr float homingOffsetMn = 10_mm;
    }

    /**
        Web Config
*/
    namespace Web {
        // This should be unique to your device. You will use this on the
        // web portal to interact with your OSSM.
        // there is NO security other than knowing this name, make this unique
        // to avoid collisions with other users
        constexpr char *ossmId = nullptr;
    }

    /**
        Font Config. These must be the "f" variants of the font to support other
       languages.
*/
    namespace Font {
        static auto bold = u8g2_font_helvB08_tf;
        static auto base = u8g2_font_helvR08_tf;
        static auto small = u8g2_font_6x10_tf;
    }

    /**
        Advanced Config
*/
    namespace Advanced {

        // After homingStart this is the physical buffer distance from the
        // effective zero to the home switch This is to stop the home switch
        // being smacked constantly
        constexpr float strokeZeroOffsetMm = 6.0f;
        // The minimum value of the pot in percent
        // prevents noisy pots registering commands when turned down to zero by
        // user
        constexpr float commandDeadZonePercentage = 1.0f;
        // affects acceleration in stepper trajectory (Aggressiveness of motion)

        constexpr float accelerationScaling = 100.0f;

    }

}

// Alias for "_mm" operator
using namespace Config::Driver::Operator;

#endif  // OSSM_SOFTWARE_CONFIG_H

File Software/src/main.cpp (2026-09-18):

#include "Arduino.h"
#include "OneButton.h"
#include "components/HeaderBar.h"
#include "esp_log.h"
#include "ossm/Events.h"
#include "ossm/OSSM.h"
#include "ossm/pages/pairing.h"
#include "ossm/state/state.h"
#include "services/board.h"
#include "services/communication/mqtt.h"
#include "services/communication/nimble.h"
#include "services/display.h"
#include "services/encoder.h"
#include "services/led.h"
#include "services/stepper.h"
#include "services/wm.h"
#include "utils/firmware_md5.h"
#include "utils/update.h"

namespace sml = boost::sml;
using namespace sml;

/*
 *  ██████╗ ███████╗███████╗███╗   ███╗
 * ██╔═══██╗██╔════╝██╔════╝████╗ ████║
 * ██║   ██║███████╗███████╗██╔████╔██║
 * ██║   ██║╚════██║╚════██║██║╚██╔╝██║
 * ╚██████╔╝███████║███████║██║ ╚═╝ ██║
 *  ╚═════╝ ╚══════╝╚══════╝╚═╝     ╚═╝
 *
 * Welcome to the open source sex machine!
 * This is a product of Kinky Makers and is licensed under the MIT license.
 *
 * Research and Desire is a financial sponsor of this project.
 *
 * But our biggest sponsor is you! If you want to support this project, please
 * contribute, fork, branch and share!
 */

OneButton button(Pins::Remote::encoderSwitch, false);

#ifdef CONFIG_APP_ROLLBACK_ENABLE
// Keep Arduino core startup from accepting a pending image before OSSM has
// initialized enough of the application to confirm it explicitly.
extern "C" bool verifyRollbackLater() { return true; }
#endif

void __attribute__((weak)) setup() {
    // Suppress verbose GPIO configuration logs
    esp_log_level_set("gpio", ESP_LOG_WARN);

    /** Board setup */
    initBoard();

    ESP_LOGD("MAIN", "Starting OSSM");

    // Display
    initDisplay();

    // Initialize header bar task
    initHeaderBar();

    // Create OSSM instance for backward compatibility (BLE command handling)
    ossm = new OSSM();

    // Initialize state machine after global state is set up
    initStateMachine();

    // The board, display, and state machine initialized successfully. Confirm
    // the running image if a rollback-capable bootloader marked it pending.
    ossmConfirmRunningImage();
    cacheSketchMd5();  // before BLE/Wi-Fi/MQTT: getSketchMD5 needs a big buffer

    // ialize LED for BLE and machine status indication
    ESP_LOGI("MAIN", "LED initialized for BLE and machine status indication");
    updateLEDForMachineStatus();  // Set initial LED state

    // // link functions to be called on events.
    button.attachClick([]() { stateMachine->process_event(ButtonPress{}); });
    button.attachDoubleClick(
        []() { stateMachine->process_event(DoublePress{}); });
    button.attachLongPressStart(
        []() { stateMachine->process_event(LongPress{}); });

    xTaskCreatePinnedToCore(
        [](void *pvParameters) {
            while (true) {
                button.tick();
                vTaskDelay(25 / portTICK_PERIOD_MS);
            }
        },
        "buttonTask", 4 * configMINIMAL_STACK_SIZE, nullptr,
        configMAX_PRIORITIES - 1, nullptr, 0);

    // Communication must remain available while homing and in motor-power
    // error states. This also makes diagnostics and recovery possible when the
    // drive supply is intentionally disconnected.
    xTaskCreatePinnedToCore(
        [](void *pvParameters) {
            ESP_LOGD("MAIN", "Initializing communication services");
            initNimble();
            initWM();
            // The MQTT TLS session competes with homing for internal RAM and
            // can leave the backward homing pass unable to start. Bring MQTT
            // and the pairing check up once the boot homing run is over
            // (capped so comms still come up if something else stalls).
            // Later re-homes pause and resume MQTT themselves.
            for (int waited = 0; waited < 1200; waited++) {
                const bool bootHomingPending =
                    stateMachine->is("idle"_s) ||
                    stateMachine->is("homing"_s) ||
                    stateMachine->is("homing.forward"_s) ||
                    stateMachine->is("homing.backward"_s);
                if (!bootHomingPending) break;
                vTaskDelay(pdMS_TO_TICKS(100));
            }
            initMQTT();
            pages::startPairingStatusCheck();
            vTaskDelete(nullptr);
        },
        "initNimbleTask", 32 * configMINIMAL_STACK_SIZE, nullptr,
        configMAX_PRIORITIES - 1, nullptr, 0);
};

void __attribute__((weak)) loop() { vTaskDelete(nullptr); };

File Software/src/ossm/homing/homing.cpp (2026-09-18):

#include "homing.h"

#include "Strings.h"
#include "homing_logic.h"
#include "constants/Config.h"
#include "constants/Pins.h"
#include "constants/UserConfig.h"
#include "ossm/Events.h"
#include "ossm/state/calibration.h"
#include "ossm/state/error.h"
#include "ossm/state/state.h"
#include "services/communication/mqtt.h"
#include "services/led.h"
#include "services/stepper.h"
#include "services/tasks.h"
#include "utils/analog.h"

#include <esp_heap_caps.h>

namespace sml = boost::sml;
using namespace sml;

namespace homing {

namespace {

// The MQTT client holds a TLS session that competes with homing for internal
// RAM. It is paused for the whole homing run and resumed once the state
// machine has left homing by any route (done, error, emergency stop).
bool mqttPausedForHoming = false;

bool isInHomingState() {
    return stateMachine->is("homing"_s) ||
           stateMachine->is("homing.forward"_s) ||
           stateMachine->is("homing.backward"_s);
}

void pauseMqttForHoming() {
    if (mqttPausedForHoming || mqttClient == nullptr) return;
    esp_mqtt_client_stop(mqttClient);
    mqttPausedForHoming = true;
}

void resumeMqttAfterHoming() {
    if (!mqttPausedForHoming) return;
    mqttPausedForHoming = false;
    if (mqttClient != nullptr) esp_mqtt_client_start(mqttClient);
}

}  // namespace

void clearHoming() {
    ESP_LOGD("Homing", "Homing started");

    // Set homing active flag for LED indication
    setHomingActive(true);

    calibration.isForward = true;

    // Set acceleration and deceleration in steps/s^2
    stepper->setAcceleration(1000_mm);
    // Set speed in steps/s
    stepper->setSpeedInHz(25_mm);

    // Clear the stored values.
    calibration.measuredStrokeSteps = 0;

    // Recalibrate the current sensor offset.
    calibration.currentSensorOffset = (getAnalogAveragePercent(
        SampleOnPin{Pins::Driver::currentSensorPin, 1000}));
}

static void startHomingTask(void *pvParameters) {
    TickType_t xTaskStartTime = xTaskGetTickCount();

#ifdef AJ_DEVELOPMENT_HARDWARE
    stepper->setCurrentPosition(0);
    stepper->forceStopAndNewPosition(0);
    stepperFrame = StepperFrame::Native;  // counter re-zeroed at home rest
    stateMachine->process_event(Done{});
    vTaskDelete(nullptr);
    return;
#endif

    pauseMqttForHoming();

    // Stroke Engine and Simple Penetration treat this differently.
    stepper->enableOutputs();
    stepper->setDirectionPin(Pins::Driver::motorDirectionPin, false);
    int16_t sign = stateMachine->is("homing.backward"_s) ? 1 : -1;

    int32_t targetPositionInSteps =
        round(sign * Config::Driver::maxStrokeSteps);

    ESP_LOGD("Homing", "Target position in steps: %d", targetPositionInSteps);
    stepper->moveTo(targetPositionInSteps, false);

    // run loop for 15second or until loop exits
    while (isInHomingState()) {
        TickType_t xCurrentTickCount = xTaskGetTickCount();
        // Calculate the time in ticks that the task has been running.
        TickType_t xTicksPassed = xCurrentTickCount - xTaskStartTime;

        // If you need the time in milliseconds, convert ticks to milliseconds.
        // 'portTICK_PERIOD_MS' is the number of milliseconds per tick.
        uint32_t msPassed = xTicksPassed * portTICK_PERIOD_MS;

        if (homing_logic::isHomingTimedOut(msPassed, 40000)) {
            ESP_LOGE("Homing", "Homing took too long. Check power and restart");
            errorState.message = ui::strings::homingTookTooLong;

            // Clear homing active flag for LED indication
            setHomingActive(false);

            stateMachine->process_event(Error{});
            break;
        }

        // measure the current analog value.
        float current = getAnalogAveragePercent(
                            SampleOnPin{Pins::Driver::currentSensorPin, 50}) -
                        calibration.currentSensorOffset;

        ESP_LOGV("Homing", "Current: %f", current);
        bool isCurrentOverLimit = homing_logic::isCurrentOverLimit(
            current, 0, Config::Driver::sensorlessCurrentLimit);

        if (!isCurrentOverLimit) {
            vTaskDelay(10);  // Increased from 1ms to 10ms to reduce CPU load
            continue;
        }

        ESP_LOGD("Homing", "Current over limit: %f", current);
        stepper->stopMove();

        stepper->setSpeedInHz(250_mm);
        // step away from the hard stop, with your hands in the air!
        int32_t currentPosition = stepper->getCurrentPosition();
        stepper->moveTo(currentPosition - sign * Config::Driver::homingOffsetMn,
                        true);

        // measure and save the current position
        calibration.measuredStrokeSteps =
            homing_logic::calculateMeasuredStroke(
                stepper->getCurrentPosition(),
                Config::Driver::maxStrokeSteps);

        stepper->setCurrentPosition(0);
        stepper->forceStopAndNewPosition(0);
        // The counter was just re-zeroed at the homed rest position: the
        // shared frame is Native again by definition.
        stepperFrame = StepperFrame::Native;

        int32_t goToPosition = homing_logic::calculatePostHomingPosition(
            sign, calibration.measuredStrokeSteps,
            UserConfig::afterHomingPosition);

        stepper->moveTo(goToPosition,true);

        // Clear homing active flag for LED indication
        setHomingActive(false);

        stateMachine->process_event(Done{});
        break;
    };

    // The forward pass hands over to the backward pass while still homing;
    // only the pass that leaves homing (or any error/stop exit) resumes MQTT.
    if (!isInHomingState()) {
        resumeMqttAfterHoming();
    }

    vTaskDelete(nullptr);
}
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

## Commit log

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2020-09-22 Fix bearing wrap
    Fixed artifact on bearing mount hole
    [OSFM bearing mount wrap V2.stl]
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2021-04-04 James' Attempt
    Maybe made it better, maybe made it worse?
    [OSSM_Main_PCB.brd, OSSM_Main_PCB.sch]
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2021-04-05 Added holes, fixed 3.3V VIO
    [ESP wiring.xlsx, OSSM_Main_PCB.brd, OSSM_Main_PCB.sch]
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2021-04-05 24v pin missing label
    [OSSM_Main_PCB.brd]
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2021-05-26 Fixed not running without WiFI
    Moved Wifi connect to a separate thread so it didn't block running the motion if it couldn't find a wifi network.
2021-05-31 Added fusion file, folder cleanup
    Fusion project is now included, PCB files moved to their own folder.
    [ESP wiring.xlsx, F Machine Base - April 2020 Release v1.f3z, OSSM_Main_PCB.brd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]
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2021-06-14 Delete OSSM Double Double.stl
    wrong folder
    [OSSM Double Double.stl]
2021-06-14 Add files via upload
    OSSM Double double adapter - now in the right folder
    [OSSM Double Double.stl]
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2021-06-30 Daily Build
    Most recent step files for those following along with the constant changes
    [Mounting bracket.step, OSSM Base.step, OSSM Middle.step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]
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2021-08-11 fixing files
    [Belt Tensioner.stl, OSSM BeltTensioner (Elims FuckIO).step]
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2021-11-06 added LED, fixed step dir pins
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2022-01-01 New mounting and improved build
    Added articulating ball head arm design.
    Improved belt clamp top and bottom, dramatically more robust, and now acts as hard stop.
    Improved retaining of m3 nuts.
    Added clamp features on bottom and cover for ballhead clamps.
    [Adjustable arm for ball head mount v2.f3d, Base plate.step, Belt Clamp.step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]
2022-01-02 Create 24mm End Effector - Alex Upgraded + James Upgraded.stl
    [24mm End Effector - Alex Upgraded + James Upgraded.stl]
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2022-01-07 Increased homing decel
    Stop faster during homing, also toned down default max speed and accel to prevent electrical issue with regen.
    [OSSM_Main.ino]
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2022-01-15 OSSM middle update
    Lengthened limit switch screw holes. changed note about limit normally open.
    [OSSM Body - Middle.stl]
2022-01-19 Added 24mm Jam nut
    Moved STLs into source files folder, added threaded parts into main folder.
    [24mm Jam Nut.stl, 24mm linear rail adapter.step, Dildo mount Double Double - 24mm threaded.stl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]
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2022-01-29 Flipped KM logo added remote top
    Finally corrected the orientation of the OSSM cover KM logo.
    Added top cover for remote - aesthetic only.
    adjusted default stroke to 3 inches and accel to 100m/s/s
    [OSSM - Body - Cover.stl, OSSM - Remote - Top Cover .stl]
2022-01-31 Actually corrected KM logo orientation
    [OSSM - Body - Cover.stl]
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2022-02-16 moved wifi reset to button input IO23
2022-02-16 fixed wifi reset to pulldown
    [OSSM_Main.ino]
2022-02-17 Added clearance to remote cover to help prevent breaking screens
    [OSSM - Remote - Top Cover .stl]
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2022-03-24 Add files via upload
    moved limit switch cable route further away from motor and made the control board side narrower.
    [nema23 motor mount-ridgev3 v14.f3d]
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2022-03-29 fixed encoder debounce updated Shicks mounting
    [4040 end cap v7.f3d, 4040 end cap v7.stl, 4040-D-Ring-Bottom.stl.stl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]
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2022-05-14 V0.201 release
    Correct configuration for non-initial setup.
    Backwards compatibility with V1 hardware not yet tested.
    [OSSM_Main.ino]
2022-05-20 Updated WiFiManager
    ESP IDF change caused issue with old WifiManager.
    [Board.gbr, BoardOutline.gbr, Bottom.gbr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]
2022-05-21 Added LED feedback to initial burn setup
    Orange LED after rainbow until Wifi connected, purple during update.
    [OSSM_Main.ino]
2022-06-22 Create OSSM High Voltage Failure.pdf
2022-10-13 Update OSSM - Body - Cover.stl
    Added OSSM logo with slightly raised text for two color printing.
    [OSSM - Body - Cover.stl]
2022-10-14 Add files via upload
    Updated to address threading issue
    [Vampix_OSSM_Tie_Down_and_Suction_Plate_v2.f3d.f3d, Vampix_OSSM_Tie_Down_and_Suction_Plate_v2.stl]
2022-10-14 Add files via upload
    Fixed thread issue
    [Vampix_OSSM_Tie_Down_and_Suction_Plate_LARGE_v2.f3d]
2022-10-14 Delete Vampix OSSM_Tie_Down_and_Suction_Plate_v2.f3d
    Replaced with new version
    [Vampix OSSM_Tie_Down_and_Suction_Plate_v2.f3d]
2022-10-14 Delete Vampix 24mm Tie Down and Suction Plate - LARGE.stl
    Removed due to incorrect thread
    [Vampix 24mm Tie Down and Suction Plate - LARGE.stl]
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2022-11-06 Stroke Engine live on OTA
    V0.21 release - live on OTA update.
    Flipped stroke engine direction to match vanilla OSSM travel
    Added Version number to startup screen.
    [OSSM_Main.ino]
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2022-11-19 Update FAQ.md
    fixed motor size
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2022-12-23 Fix for WiFi connection
    Added wifi thread to launch config hotspot on boot without blocking normal functioning.
    Also added blocking hotspot config and wifi credential reset is you hold down the PCB button at boot.
    [OSSM_Main.ino]
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2023-01-11 Fusion 360 f3d file for base of OSSM that can be machined
    Here is a machinable version of the OSSM base. I recently posted about it and was asked by Vampix to share it with the community this way.
    [OSSM Base machinable v2.f3d]
2023-03-19 Update README.md
    Fixed pulley size
2023-03-19 Update OSSM - Belt clamp - Tensioner end.stl
    Added new tensioner design
    [OSSM - Belt clamp - Tensioner end.stl]
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2023-04-21 Create hinge-plate.stl
    Exported hinge-plate.stl from the source f3d files as the STL was missing
    [hinge-plate.stl]
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2023-05-04 Delete SATC - Improved rear tensioner v3.stl
    Deleted to move into correct folder
    [SATC - Improved rear tensioner v3.stl]
2023-05-16 Update README.md
    updating the Servo Wiring diagram to have the correct dip switches
2023-05-17 Update README-update-draft.md
    Adding parts sources, formatting changes, and replacing the servo wiring image with the corrected version
2023-05-17 Update README-update-draft.md
    Adding parts sources including octopart, formatting changes, and replacing the servo wiring image with the corrected version
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2023-05-17 Update readme.md
    fixing broken image and adding links to purchase the ballhead mounts from neewer and ulanzi
2023-05-17 Update readme.md
    fixing broken image and adding links to purchase the ballhead mounts from neewer and ulanzi and formatting changes
2023-06-18 Remixed tie down and suction plate
    For larger toys and fatter rope with some holes to help really hold things down.
    [OSSM_Tie_Down_and_Suction_Plate-MrNevermoreRemix.f3d, OSSM_Tie_Down_and_Suction_Plate-MrNevermore_Remix.stl]
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2023-09-20 Update README.md
    Fixed some broken links for motor details.
2023-10-29 Updated PCB schematic
    Updated to the latest V2.2 board design.
    Fixed silkscreen typo, added more labels, new step-dir header for improved wiring.
2023-10-30 Added Remote PCB Files
    Added remote PCB files and moved old rev's to archive folder for clarity.
    [ESP wiring.xlsx, Eagle OSSM Ref Board PCB V1.brd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]
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2023-12-04 STL updates, Minor SW improvements
    Updated many STL files to improve fit and fixed minor SW issues.
    See full update notes at https://unbox.ossm.tech/#updates
    [OSSM - Belt clamp - Bottom.stl, OSSM - Belt clamp - Tensioner End - SATC [ALTERNATE] - Improved rear tensioner v3.stl, OSSM - Belt clamp - Tensioner end.stl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]
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2023-12-11 Aj/repair stroke engine. (#52)
    * restore stroke engine from lib directory
    * fix: stroke engine write collision
    [main.cpp]
2024-01-12 Updated source and step files (#56)
    Now have master assemblies containing all step files as well as a single fusion project.
    [0.75 inch EMT Pipe Mount.step, 24mm linear rail adapter.step, Adjustable arm for ball head mount v2.f3d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]
2024-02-21 Basic Mount and Flange
    Added Flange mounting files to support better mounting of toys without suction cup or vac-u-lock
    Add printed files for new basic mount - to replace ball head mount.
    [Adjustable arm for ball head mount v2.f3d, Extension arm for ball head.stl, Mounting base left side.stl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]
2024-02-25 Mount details added for basic and full extrusion stand (#60)
    * Added STLs
    STL for basic and full extrusion stand added.
    * Update readme.md
    * Update README.md
    * Create Gold-Motor.md
    * Added basic mount pieces and enlarged feet
    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
    [Adjustable arm for ball head mount v2.f3d, Extension arm for ball head.stl, Mounting base left side.stl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]
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2024-04-10 Minor STL tweak
    Improved tensioner fit on M5 nut.
    Enlarged Extrusion mount foot
    [OSSM - Belt clamp - Tensioner end.stl, OSSM - Extrusion Mount - Foot.stl]
2024-04-18 Remove Serial and LogDebug logging. (#66)
    * update the test directory structure
    * fix: remove Serial log and LogDebug
    [main.cpp]
2024-04-19 State machine (#68)
    * temp
    * test precommit
    * Start using state machine for initialization
    * Start using state machine for initialization
    [partition.csv]
2024-04-20 State Machine; resolve circular references update boost::sml (#69)
    * fix the circular reference issues
    * update boost::sml library
    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
    [main.cpp, sml.hpp]
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2024-04-24 fix: port over changes from Alex's branch (#74)
    [Config.h]
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2024-04-30 fix: make display thread safe (#77)
    [OSSM.cpp]
2024-04-30 fix: make display thread safe v2 (#78)
    fix: make display thread safe
    [OSSM.cpp]
2024-05-01 Threaded adapters and main body
    The end effectors threaded right up to the first screw mounting hole on the rail thread piece - which caused a lot of stress and could crack along that point.
    Extended the thread engagement 6mm past that hole for more strength.
    Added features to prevent linear bearing rotation to help keep m3 mounting screws from loosening with sliding.
    [OSSM - Body - Bottom.stl, OSSM - Toy mount - Dildo mount Double Double (vac-u-loc)- 24mm threaded.stl]
2024-05-04 revert master to production stable (#81)
    * revert master to production stable
    * revert master to production stable
    * revert master to production stable
    [partition.csv]
2024-05-27 AJ / Development (#82)
    Major Refactor for the latest release.
    This has been in a two week alpha.
    [partition.csv]
2024-06-15 PCB Schematic and mount nut fit improvements
    Added V2.3 schematic and source files.
    Improved fit on m3 and m5 nuts on tensioner and belt clamp.
    [OSSM - Belt clamp - Tensioner end.stl, OSSM - Belt clamp - Top.stl, OSSM - Extrusion Mount - PCB Mounting Box.stl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]
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2024-08-05 Removed bearing alignment boss
    Small boss on linear rail could cause minor cracking if not aligned to rail correctly. Removed this and tightened up bearing mounting holes instead by additional 0.1mm.
2024-08-16 Add 57AIM30 and 42AIM30 info to docs (#108)
    * Add 57AIM30 and 42AIM30 info to docs
    * fix formatting error
    * Change references to be 57AIM30-first
    New format in documentation is 57AIM30 (Gold Motor)
    Make it more clear that "Gold Motor" is name as sold by RD
    Fix typo spotted by armpitMFG
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2024-11-22 fixes to PCB sources (#147)
    Fixing error in schematic, where in DC power circuit is wrong, connecting in and out of current sensing chip. PCB layout not changed, only switched nets of CS_* traces, vias, and copper pours to accommodate changes. Updated pdf file of schematic.
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2025-01-21 CAD Project - Fusion (#153)
    * CAD Project - Fusion
    * Introduce 'OSSM - Mod' Template Document
    * Readme update, template tweak
    * Template tweak
    * Template tweak, readme tweak
    [5x11x4 Bearing.f3d, 5x11x4 Bearing.stp, Assets - Motor - 57AIM30.f3d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]
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2025-02-27 CAD Project - 3030 Stand Spacer add 1mm washer tolerance, Actuator Body tweaks (#158)
    [(M6 x 15 Cap Head Screw,M6 x 20 Cap Head Screw for 4040 Extrusion).f3d, (M6 x 15 Cap Head Screw,M6 x 20 Cap Head Screw for 4040 Extrusion).stp, 3030 Corner Bra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]
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2025-04-06 OSSM 2025 Update
    Default build documentation and files updated to:
    57AIM30 "Gold Motor"
    PitClamp v1.1 Mounting Ring+Base
    3030 Extrusion Stand with Pivot Plates
    [24mm linear rail adapter.step, Bambu - PitClamp Mini - Print-In-Place.3mf, Bambu - PitClamp Mini.3mf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]
2025-04-07 Reinforced PitClamp Mini - OSSM Mod (#170)
    [OSSM - Base - PitClamp Mini - Dogbone Bolts.stl, OSSM - Base - PitClamp Mini - Dogbone Bolts.stp, OSSM - Base - PitClamp Mini - Dogbone Nuts.stl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]
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2025-04-12 Add additional clearance for M6 cap and M5 holes
    [OSSM - Base - PitClamp Mini - Lower V1.1.stl, OSSM - Base - PitClamp Mini - Lower V1.1.stp, OSSM - Mounting Ring - PitClamp Mini - 57AIM V1.1.stl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]
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2025-05-07 PitClamp v1.1 tweaks (Increase gaps for print-in-place handle, True 30mm width no margin for SideMount, Extrusion Ring minor bugfixes and rename)
    [OSSM - Base - PitClamp Mini - Handle.stp, OSSM - Base - PitClamp Mini - Lower V1.1 - Reinforced SideMount 3030.stl, OSSM - Base - PitClamp Mini - Lower V1.1 - 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]
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2025-05-16 Orientation and name fixes
    [OSSM - Toy Mounting - Dildo Ring 2.5in.stp, OSSM - Toy Mounting - Dildo Ring 2in.stp, OSSM - Toy Mounting - Double Double (Vac-U-Lock) - 24mm Threaded.stl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]
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2025-08-14 Correct orientation of Middle Pivot
    [OSSM - Actuator - Body - Middle Pivot.stl]
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2025-09-26 Clean up characteristics and offset by x1000 to reserve space for system (#185)
    [partition.csv]
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2025-09-28 Led status indicator framework (#189)
    * Initial working draft for RGB LED status effects
    * Revert "GITBOOK-5: No subject"
    This reverts commit 8bac66ffa4dfa923819a25ae2c82f6ddb72d49ac.
    * Bootooping on some hardware. Reducing homing cycle from 1ms to 10ms (#188)
    * LED dimming if BLE not connected after 30 seconds.
    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
    [board.cpp, led.cpp, main.cpp]
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2025-10-29 Fix non-manifold object warning and force print setting defaults at the object-level
2025-11-10 fix post merge action
    [OSSM.h]
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2026-02-12 Wifi module polish, added the ability to reset connection and fixed some bugs causing a crash
    [OSSM.h]
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2026-02-15 Reset speedBLE after chaning modes
    [OSSM.h]
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2026-02-23 Same issue... any motion is spamming nimble updates to connected devices.
    [OSSM.cpp]
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2026-02-27 Reset queue when launching streaming mode
    [streaming.cpp]
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2026-03-02 Fix MQTT local sync
    [OSSM.cpp, OSSM.h]
2026-03-02 Fix - does connect
    [main.cpp]
2026-03-02 Fix and fingerprint
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2026-03-03 docs: migrate SaladDressing mod content to documentation site
    - Add motor-cover.mdx and dp-attachment.mdx pages with hero images
    - Enrich capstan.mdx with MGN12H vs HG20 comparison, tabbed BOMs,
    inline fastener lists, assembly guide links, and full CAD file links
    - Add "Printed parts and CAD files" sections with GitHub links to all
    STEP/3MF/STL files across suction-cup-bracket, weight-plate, and
    quick-change-toy-mount pages
    - Co-locate new hero images as webp in _images/ directory
    - Register new pages in docs.json
    - Replace broken Pictures/ image refs in source READMEs with docs links
    Made-with: Cursor
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2026-03-11 Fix MQTT connection and icons
    [menu.cpp, pattern_controls.cpp, play_controls.cpp]
2026-03-23 Fix hardware test homing slamming into hard stops by suppressing verbose GPIO logs
    Without esp_log_level_set(gpio, ESP_LOG_WARN), the ESP-IDF GPIO/ADC
    drivers emit debug logs on every analogRead() call during the homing
    current-sensing loop. Each log blocks on Serial output, starving the
    loop and delaying stall detection — causing the motor to grind against
    the hard stops for hundreds of milliseconds before stopping.
    Production (main.cpp) already suppresses these logs. Adding the same
    suppression to the test brings homing behavior in line with production
    and reduces test runtime from ~138s to ~53s.
    [main.cpp]
2026-05-07 Fix cross-mode out-of-bounds rush by standardizing stepper direction polarity
    The setDirectionPin polarity differed between OSSM core and the StrokeEngine
    library and was never reset across mode transitions:
    services/stepper.cpp:11 (boot) setDirectionPin(pin, false)
    ossm/homing/homing.cpp:56 (homing) setDirectionPin(pin, false)
    StrokeEngine.cpp:36 (Stroker.begin()) setDirectionPin(pin, true)
    After a strokeEngine pattern, the polarity stayed `true` because nothing on
    the menu/streaming path reset it. Streaming math (which targeted negative
    counter values for "extend" under the OSSM-canonical polarity) now drove the
    rod in the opposite physical direction. Switching from a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
    [homing.cpp, main.cpp, stepper.cpp]
2026-06-14 Fixes mid-rail logic. Aligns with other modes
    [streaming.cpp]
2026-06-17 Migrate OTA from CloudFront/Bubble to Supabase
    The WiFi OTA fetched firmware from a legacy CloudFront origin and asked a
    Bubble endpoint whether to update. That origin is no longer maintained, so
    devices updated to a stale 1.0.16 and newer units could be downgraded.
    Rewrite update.h to fetch version.json from the Supabase production channel
    (the same source the webflasher uses), compare the version on-device, and
    download firmware.bin over validated HTTPS via esp_https_ota. The device only
    updates when the remote build is strictly newer, which removes the downgrade.
    Add structs/Version.h for the numeric version used in the comparison. The
    state machine guard and action (isUpdateAvailable,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
2026-06-18 Run OTA check and download in a dedicated task
    Selecting Update ran the TLS version check and firmware download inline
    in the state machine, which executes on the button task (~4 KB stack).
    The mbedTLS handshake needs far more, so it overflowed the stack and
    rebooted the device.
    Move the check and the OTA into a dedicated FreeRTOS task with a
    TLS-sized stack (mirrors pairingTask). The state machine now just spawns
    the task and waits for an UpdateUnavailable event, which the task posts
    when there is no newer version or the update fails; on success the task
    reboots into the new firmware. The state machine no longer does any TLS
    work itself.
    Also log free heap and largest free block at WARN l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
2026-06-18 Run OTA in a dedicated task and pause MQTT during it
    Move the check and OTA into a dedicated FreeRTOS task with a TLS-sized
    stack (mirrors pairingTask). The state machine spawns the task and waits
    for an UpdateUnavailable event, which the task posts when there is no
    newer version or the update fails; on success the task reboots into the
    new firmware. The state machine no longer does TLS itself.
    Stop the MQTT client for the duration of the update and restart it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
2026-06-18 Mirror production firmware to the legacy CloudFront path on promotion
    Old WiFi-OTA devices download firmware from the legacy CloudFront/S3 path
    (bucket ossm-update), not Supabase. That path was updated by hand and got
    forgotten, freezing the fleet at an old build. Make the legacy upload an
    automatic step of Release Alpha as Production so it stays in sync on every
    promotion and cannot silently drift again.
    After the Supabase production upload, log into AWS via the OIDC role and
    aws s3 cp the firmware to s3://ossm-update/firmware.bin. The Supabase
    publish runs first, so if the S3 step fails (missing role permission)
    production is still correct and the failure is non-destructive.
    Co-Authored-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
2026-07-24 Prevent repeated firmware update loops (#302)
    [main.cpp]
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2026-07-27 Expose and validate unified BLE controls (#308)
    * Make BLE control available for hardware recovery
    * Expand OTA capacity for 16 MiB controllers
    [min_spiffs.csv]
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2026-08-27 Fix simple penetration polarity test
    [main.cpp]
2026-08-29 Create OSSM High Voltage Failure.pdf
    (cherry picked from commit f6ac487e2e6d59ae0621894d15f02bcfdfe43bf7)
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2026-08-29 OSSM 2025 Update
    (cherry picked from commit 52537c0896eaef83fd9771dcc633903c7aa6a8ab)
    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
    [24mm linear rail adapter.step, BasePlate_24mmThread.STEP, DoubleDouble to the moon v2.step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]
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2026-08-29 Led status indicator framework (#189)
    (cherry picked from commit 5c300139cd72c8eb12fcf22af31e000c4b543e66)
    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
2026-08-29 PitClamp Mini Release
    (cherry picked from commit afd4ffeb3c6330a36cd3021191cb0831c41ef981)
    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
    [Bambu - PitClamp Mini - Print-In-Place.3mf, Bambu - PitClamp Mini.3mf, PitClamp Mini - Base - Folding - Lower.step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]
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2026-08-29 Create hinge-plate.stl
    (cherry picked from commit b99a8364d6a9dc164f44f7308eb48a824a6a074a)
    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
    [hinge-plate.stl]
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2026-08-29 Basic Mount and Flange
    (cherry picked from commit edb71a19dfc33d6ff8abbbf66f563d2e9e24c06a)
    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
    [Adjustable arm for ball head mount v2.f3d, Extension arm for ball head.stl, Mounting base left side.stl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]
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2026-08-31 hotfix: swap actuator STL variants
    [OSSM - 24mm Clamping Thread - Belt Clamp.stl, OSSM - 24mm Clamping Thread - End Effector.stl, OSSM - 24mm Thread.stl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]
2026-08-31 Revert "hotfix: swap actuator STL variants"
    [OSSM - 24mm Clamping Thread - Belt Clamp.stl, OSSM - 24mm Clamping Thread - End Effector.stl, OSSM - 24mm Thread.stl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]
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2026-09-11 OSSM: pairing and firmware update from a BLE trigger, TLS that survives BLE and MQTT (RAD-2158)
    - accept go:pairing, go:update and go:restart over BLE from any state
    - one TLS path that pauses MQTT, checks the free-memory budget and refuses loudly
    - dynamic mbedTLS buffers so a handshake fits next to MQTT and a BLE central
    - cache the sketch MD5 at boot; getSketchMD5 aborted the device under load
    - pause MQTT before creating the update and pairing tasks and check the result
    - state JSON built with ArduinoJson; optional error, pairingCode, isPaired, targetVersion
    - failure and update-available pages with a reason
    - native tests for the BLE command grammar and the state JSON
    [OSSM.cpp, OSSM.h]
2026-09-17 hotfix: keep MQTT out of homing and fail loudly when the homing task cannot start
    Since 1.0.57 the MQTT TLS session comes up while homing runs and the
    backward pass never completes, leaving the OSSM on the measuring stroke
    screen with no timeout. Defer MQTT and the pairing check until boot
    homing is over, pause and resume MQTT around later re-homes, and check
    the homing task creation so a failure raises the homing error instead
    of hanging.
    [homing.cpp, main.cpp]
2026-09-17 Revert "Fix cross-mode out-of-bounds rush by standardizing stepper direction polarity (#273)"
    This reverts commit 976a847b0bfd33a4ac802fa4b512b4c8606571ce, reversing
    changes made to 8f8ac138dca04d2b90dca5a8e783d2ff0fd6062d.
    [homing.cpp, main.cpp, stepper.cpp]
2026-10-20 hotfix: publish community firmware to Supabase instead of official releases
    This repository no longer produces official R+D firmware; official releases
    come only from researchanddesire/OSSM. Builds of main and staging now go,
    unsigned, to the public ossm-firmware bucket under kinkymakers/ (V2 per
    branch, plus V1 on main), with an immutable short-SHA folder per build and a
    registry rebuild against the explicit production project ref.
    Remove the official-only finalize and legacy alias workflows, which needed
    the release credentials that were withdrawn from this repository, and record
    the community role in AGENTS.md.
2026-10-20 Pin FastLED for the legacy 4 MB build
    The legacy 1.0.39 source asks for FastLED ^3.6.0, and October FastLED releases no longer compile against it. Pin 3.10.3, the version the current firmware uses, which builds V1 within its 4 MB application limit.

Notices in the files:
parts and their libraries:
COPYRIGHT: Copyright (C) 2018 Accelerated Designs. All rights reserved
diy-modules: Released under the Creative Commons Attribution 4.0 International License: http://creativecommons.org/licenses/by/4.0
